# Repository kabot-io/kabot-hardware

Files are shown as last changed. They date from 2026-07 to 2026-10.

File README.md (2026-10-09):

# Kabot Hardware

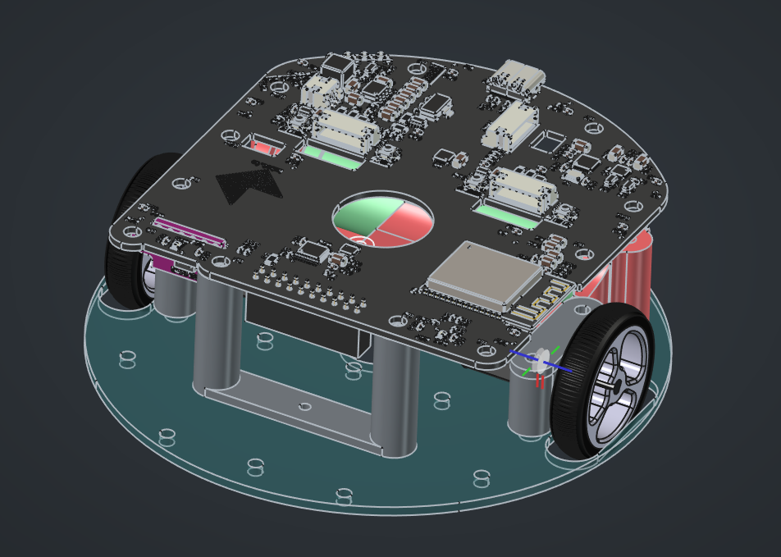
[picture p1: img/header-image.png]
Kabot robot


Kabot is an open-source, compact educational mobile robot. This repository contains its mechanical, electronic, and hardware production files.

## Project status

The hardware prototype is complete.

## FOSS toolchain

The hardware was designed entirely with free and open-source software (FOSS):

- [FreeCAD 1.1.1](https://www.freecad.org/) for the mechanical design
- [KiCad 10.0.4](https://www.kicad.org/) for the electronic design

Using these versions is recommended for the best compatibility with the source files.

## BOM

The mechanical parts are designed using [FreeCAD](https://www.freecad.org/) and 3D printed with some little exceptions, which were not viable to print due to the low cost of China-sourced parts, that is (amount for 10 robots):

- [Wheels](https://www.aliexpress.com/item/1005006221405033.html) - 20pcs
- [Torx self-tapping screws](https://www.aliexpress.com/item/1005011545930370.html) - 100pcs
- [N20 Gearmotors with 7CPR encoders](https://www.aliexpress.com/item/1005007102441781.html) - 20pcs
- [ToF distance sensor](https://www.aliexpress.com/item/1005008119148487.html) - 10pcs
- [Motor to PCB cables](https://www.aliexpress.com/item/1005007277030322.html) - 20pcs

## Electronics

The electronics has been designed using [KiCad](https://www.kicad.org/) and consist of few distinct sections (however, on a single PCB).

### Processing section  
Based on the [ESP32-S3-N16R8 MCU on Wroom-1 module](https://documentation.espressif.com/esp32-s3-wroom-1_wroom-1u_datasheet_en.pdf), which is responsible for communication with the PC, fetching data from the sensors, and executing control messages - driving the motors.

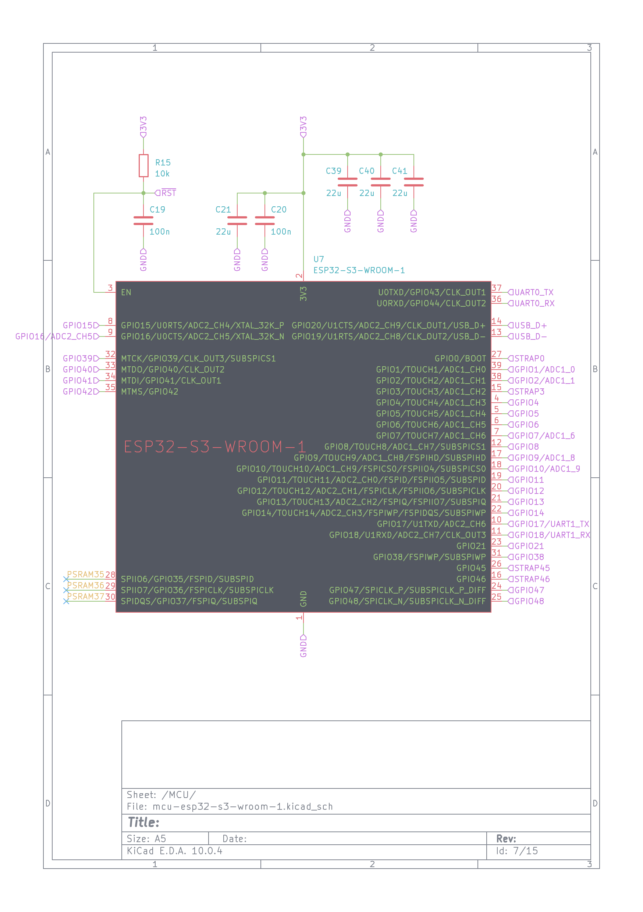
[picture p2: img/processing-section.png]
Processing section schematic


This MCU has a [built-in USB JTAG](https://docs.espressif.com/projects/esp-idf/en/stable/esp32s3/api-guides/jtag-debugging/index.html) interface, which allows for flashing and debugging the robot firmware without the need of *any* external tools, besides USB-C cable. 

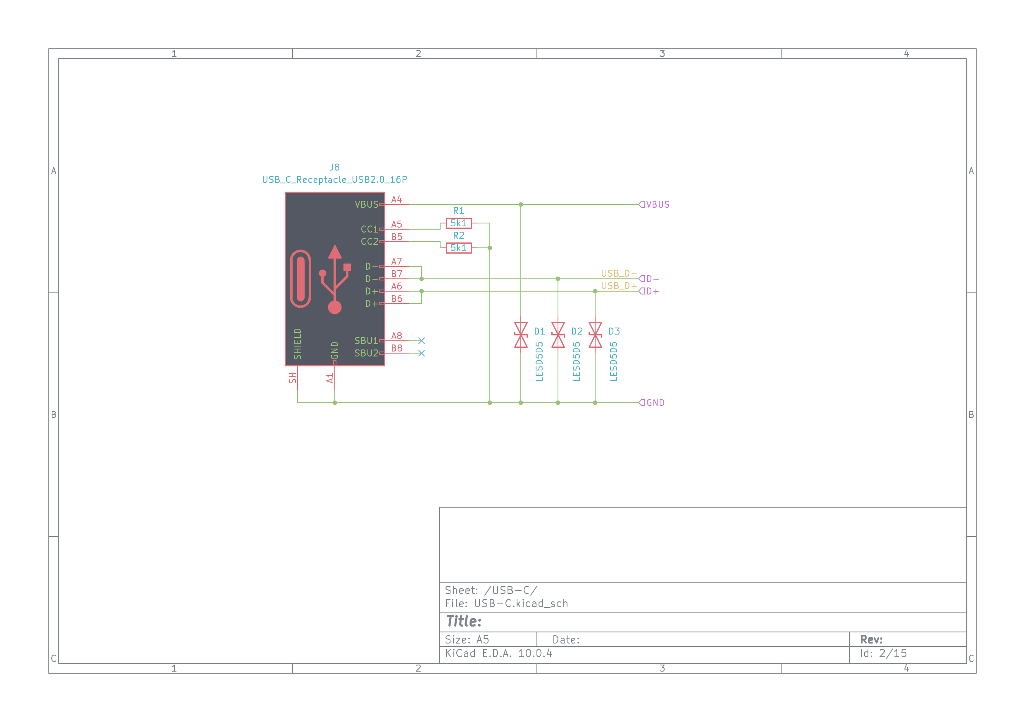
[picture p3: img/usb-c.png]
USB-C schematic


There is also onboard USB HUB ([CH334F](https://cdn-learn.adafruit.com/assets/assets/000/131/435/original/CH334DS1.PDF?1721660148)) and USB-to-serial adapter ([CH343P](https://cdn-learn.adafruit.com/assets/assets/000/134/549/original/CH343DS1.PDF?1737477957)), which allows for connecting to the robot over the raw UART interface, which exposes [first-stage bootloader](https://docs.espressif.com/projects/esp-idf/en/stable/esp32s3/api-guides/bootloader.html) logs, and a connector which allows for splitting the USB-C lanes, and injecting offboard processing units, such as embedded Linux board (instead of the beefy PC, to make the robot self-contained if needed) 

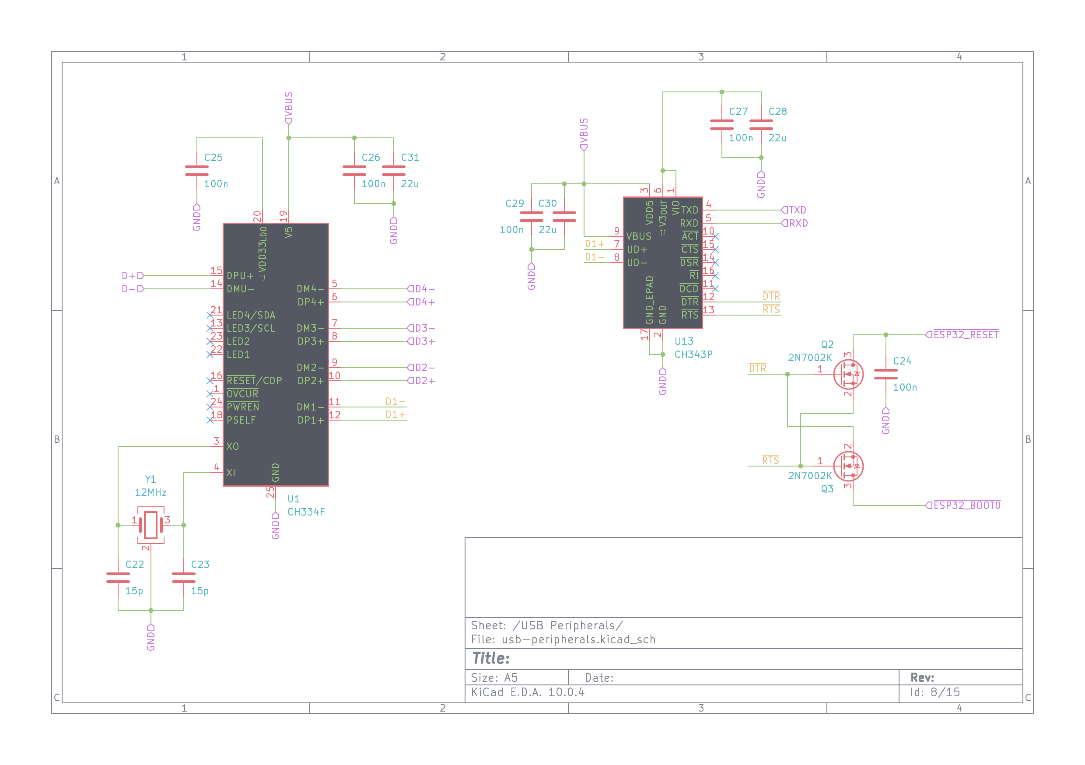
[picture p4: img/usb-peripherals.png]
USB peripherals schematic


### Power section  
The USB-C connector that is used to program the robot, is also used to charge the robot built-in battery, which is a single Lithium-Ion 18650 sized cell. The same chip is also responsible for stepping the battery voltage up to 5V, which is then fed to the motor drivers to have somehat stable motor power supply, and stabilized to 3.3V for the MCU. The chip is the thing used in powerbanks - [INJOINIC IP5306](https://www.lcsc.com/datasheet/C181692.pdf).

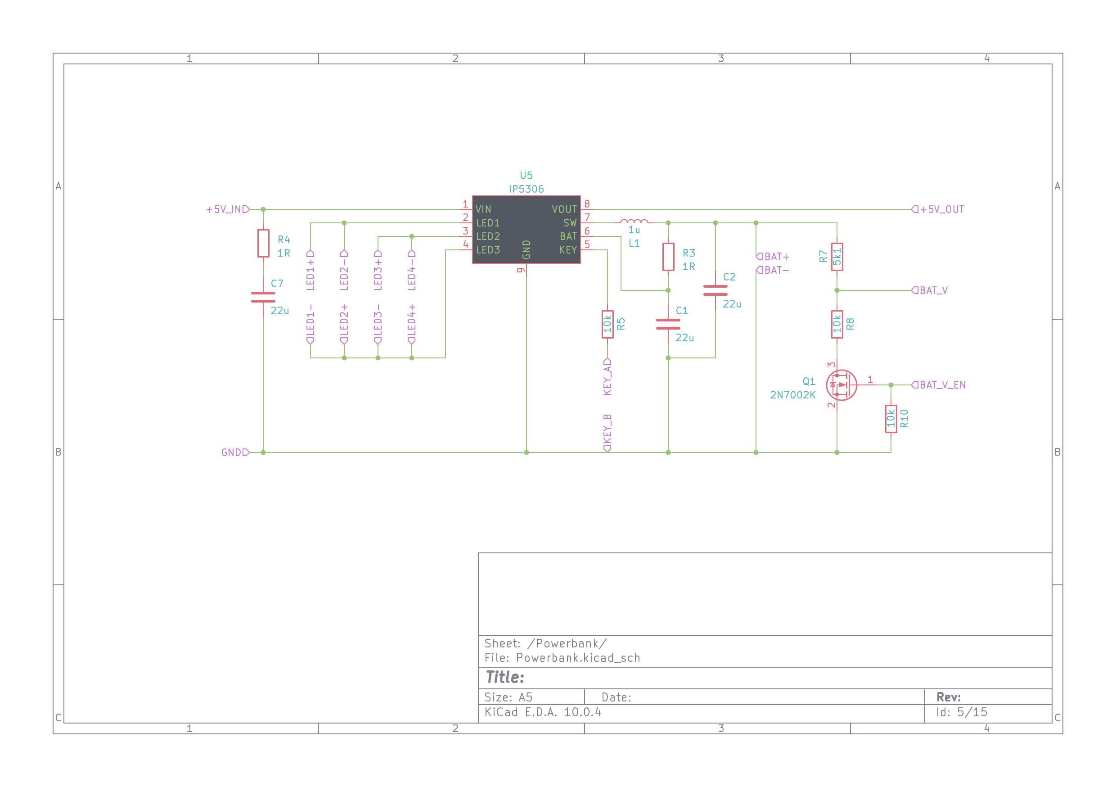
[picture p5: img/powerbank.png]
Powerbank schematic


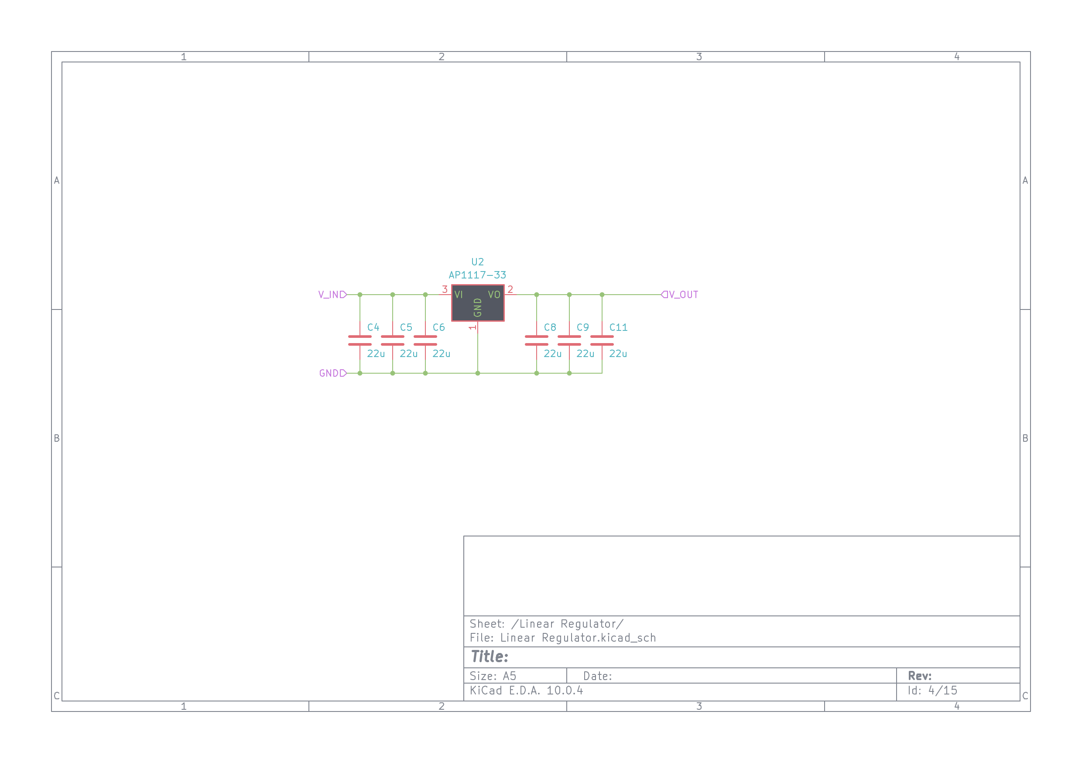
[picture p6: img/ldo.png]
LDO schematic


Motors are driven by two [DRV8837](https://www.ti.com/lit/ds/symlink/drv8838.pdf) motor drivers (up to 1.8A per motor). Each motor driver is supplied via [INA219](https://www.ti.com/lit/ds/symlink/ina219.pdf) I2C Current/Power monitor. The motors are chinese [N20 sized 298:1 micro gearmotors, equipped with magnetic incremental encoders](https://pl.aliexpress.com/item/1005007102441781.html). The power supply branch for the rest of the system also has it's own IN219 sensor. There is also voltage divider connected directly do the battery terminals (or rather semi-directly - via a switch that gets opened when the robot is not powered up, to avoid entirely draining the battery). 

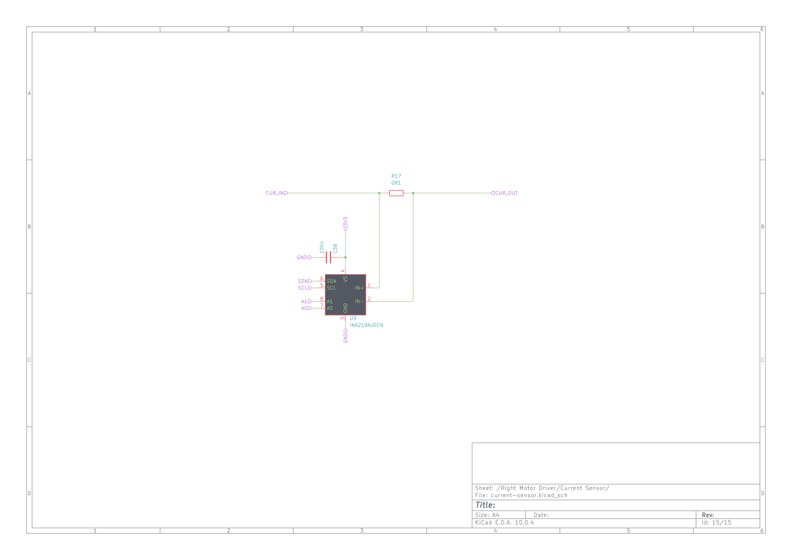
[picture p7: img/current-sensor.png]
Current sensor schematic


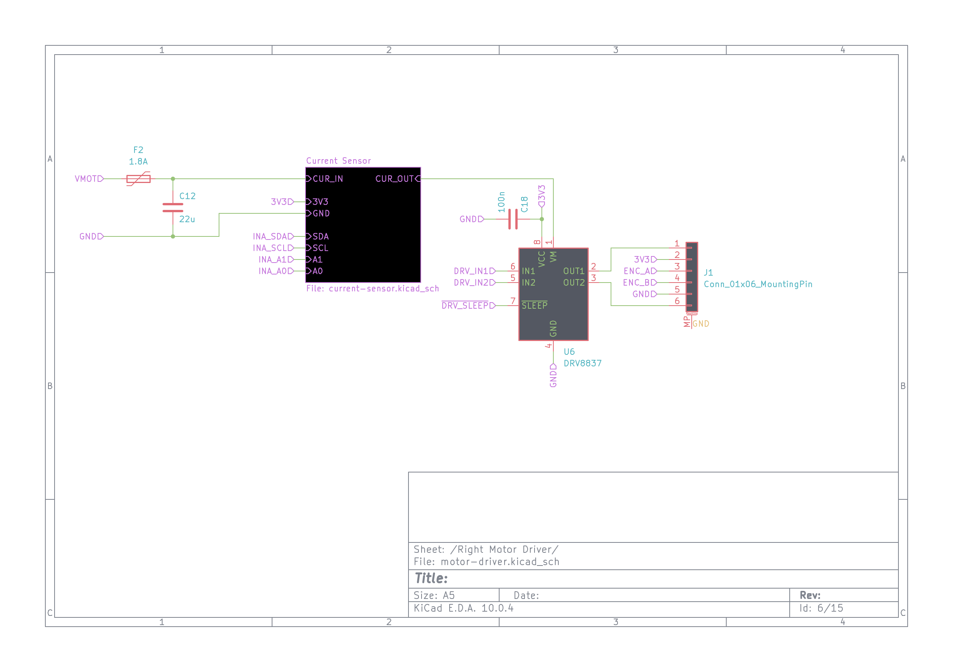
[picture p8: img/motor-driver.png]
Motor driver schematic

### Sensors section  

Besides the current sensors and encoders, robot has a bunch of on-board sensors:
- 6 Degrees of Freedon Inertial Measurement Unit: [TDK ICM-42670-L](https://datasheet.lcsc.com/datasheet/pdf/874d19cb3cf7cf4a72e58391bfc479df.pdf)
- 3 Degrees of Freedom Magnetometer: [MEMSIC MMC5603NJ](https://www.lcsc.com/datasheet/C404328.pdf)
- dual visible light sensors (left and right): [LITEON LTR-303-ALS](https://www.lcsc.com/datasheet/C364577.pdf)
- distance sensor - [ST VL53L0X](https://www.st.com/resource/en/datasheet/vl53l0x.pdf) on the GY-530 footprint module - this allows for supplying different distance sensors, sucha as 8x8 grid [ST VL53L5X](https://www.st.com/resource/en/datasheet/vl53l5cx.pdf) ToF sensor

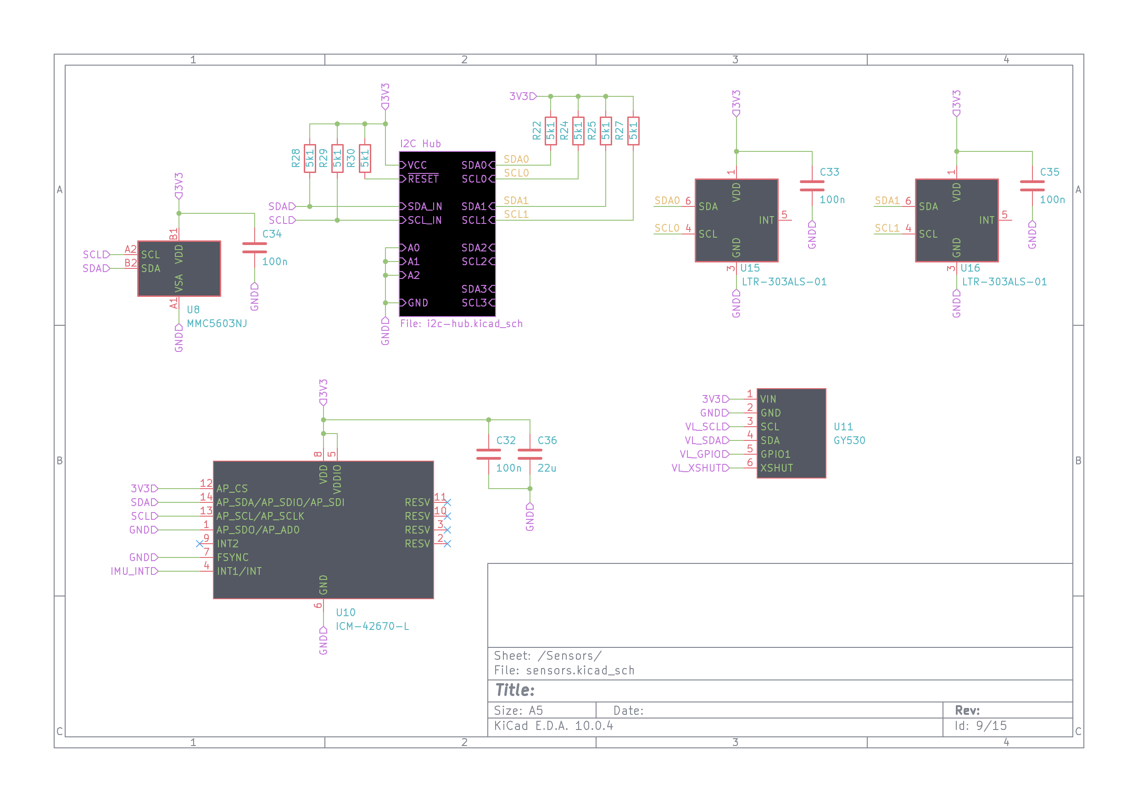
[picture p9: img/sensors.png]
Sensors schematic

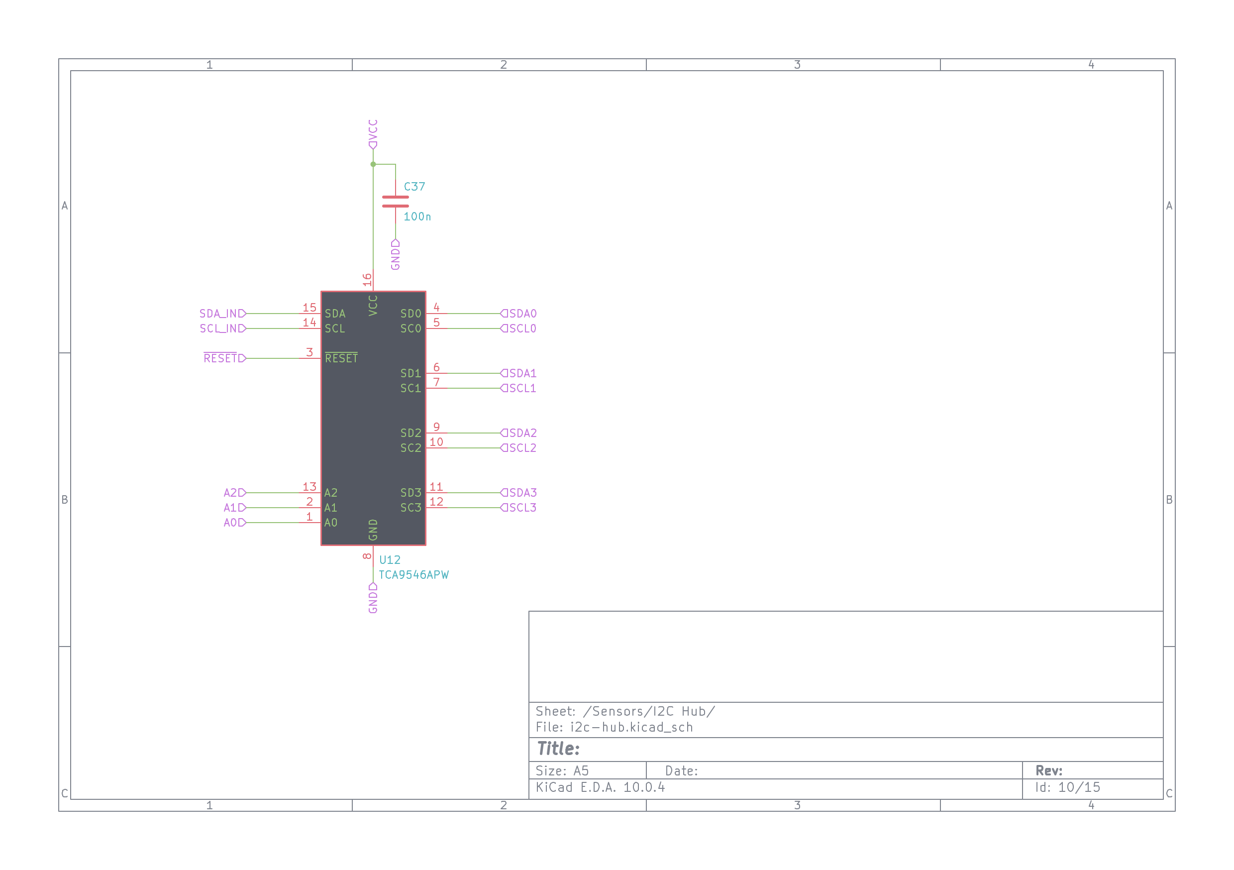
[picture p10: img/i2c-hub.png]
I2C hub schematic


These allow for implementing a wide variety of algorithms - from simple [BEAM](https://en.wikipedia.org/wiki/BEAM_robotics)-like photovores, trough IMU sensor fusion up to localization and mapping.

The board also supplies a bunch of addresable RGB LEDs.

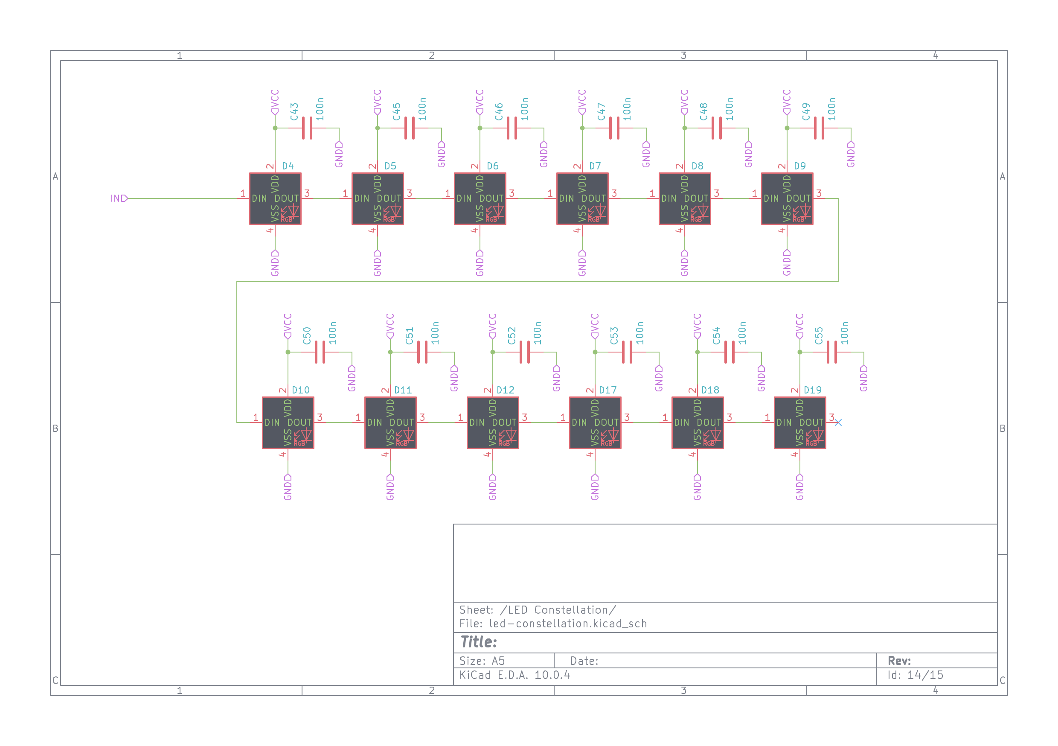
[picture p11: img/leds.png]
LEDs schematic


## Repository structure

| Directory | Contents |
| --- | --- |
| [`freecad/`](freecad/) | FreeCAD mechanical source files for the chassis, battery holder, motor mounts, wheels, and related parts. |
| [`kicad/`](kicad/) | KiCad schematics, PCB layout, symbols, footprints, and supporting EDA files. |
| [`production/`](production/) | Files used to manufacture the PCB and print the chassis, including Gerber and drill files, a bill of materials (BOM), and pick-and-place data. |

## License

Copyright 2026 Krzysztof Pochwała.

The hardware design files are available under the [Creative Commons Attribution-NonCommercial-ShareAlike 4.0 International license](LICENSE.md) (CC BY-NC-SA 4.0). You may share and adapt the files with attribution, for non-commercial purposes, provided adaptations are distributed under the same license.

## More information

Visit [kabot.io](https://kabot.io/).

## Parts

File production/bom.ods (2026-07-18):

 | version | qty | link | Price @ lot | Price @ 1 | need | price sum
Motor + encoder | 50RPM | 1 | https://pl.aliexpress.com/item/1005007571722097.html | 6,53 | 6,53 | 2 | 13,06
battery | 10pcs | 10 | https://pl.aliexpress.com/item/1005008078553867.html | 24,91 | 2,491 | 1 | 2,491
wheels | white | 10 | https://pl.aliexpress.com/item/1005006221405033.html | 4 | 0,4 | 2 | 0,8
acc+gyro | ICM-42670-L | 1 | https://www.lcsc.com/product-detail/C49073546.html | 1,86 | 1,86 | 1 | 1,86
magnetometer | MMC5603NJ | 5 | https://www.lcsc.com/product-detail/C404328.html | 1,44 | 0,288 | 1 | 0,288
current sensor | INA219 | 10 | https://www.lcsc.com/product-detail/C87469.html | 6,3 | 0,63 | 2 | 1,26
motor driver | DRV8837 | 5 | https://www.lcsc.com/product-detail/C191000.html | 0,57 | 0,114 | 2 | 0,228
shock absorber | M3 White 50pcs | 50 | https://pl.aliexpress.com/item/1005003323071003.html | 2,08 | 0,0416 | 4 | 0,1664
filament | PETG-BK-3KG | 3000 | https://pl.aliexpress.com/item/1005007633497332.html | 36,86 | 0,0122866666666667 | 200 | 2,45733333333333
8x8 tof VL53L5X |  | 1 | https://pl.aliexpress.com/item/1005009716186025.html | 9,79 | 9,79 | 1 | 9,79
ESP32 | ESP32-S3-WROOM-N16R8 | 1 | https://www.lcsc.com/product-detail/C2913202.html | 5,21 | 5,21 | 0 | 0
Camera | OV3660 | 1 | https://pl.aliexpress.com/item/1005008605438383.html | 3,39 | 3,39 | 1 | 3,39
Motor Connector | ZX-ZH1.5-6PWT | 5 | https://www.lcsc.com/product-detail/C19272409.html | 0,33 | 0,066 | 2 | 0,132
Battery Connector | ZX-ZH1.5-2PWT | 10 | https://www.lcsc.com/product-detail/C19272405.html | 0,44 | 0,044 | 1 | 0,044
Motor Cable | 10CM 10PCS Double head 6p | 10 | https://pl.aliexpress.com/item/1005007277030322.html | 4,37 | 0,437 | 2 | 0,874
Battery Cable | 10CM 10PCS Single head 2p | 10 | https://pl.aliexpress.com/item/1005007277030322.html | 1,66 | 0,166 | 1 | 0,166
Sensor Connector | MF254VS-12-20-0743 | 1 | https://www.lcsc.com/product-detail/C911394.html | 0,53 | 0,53 | 1 | 0,53
RGB LED | WS2812 | 5 | zwrócić uwagę na zasilanie 3.3V | 0,5 | 0,1 | 7 | 0,7
Powerbank | IP5306 | 5 | https://www.lcsc.com/product-detail/C181692.html | 1,41 | 0,282 | 1 | 0,282
light sensor |  |  | TEMT6000, ale drogi |  |  | 2 | 0
 |  |  |  |  |  |  | 0
17,2033333333333 |  |  |  |  |  |  | 0
 |  |  |  |  |  |  | 0
 |  |  |  |  |  |  | 0
 |  |  |  |  |  |  | 0
 |  |  |  |  |  |  | 0
 |  |  |  |  |  |  | 0
 |  |  |  |  |  |  | 0
 |  |  |  |  |  |  | 0
 |  |  |  |  |  |  | 0
 |  |  |  |  |  |  | 0
 |  |  |  |  |  |  | 38,5187333333333

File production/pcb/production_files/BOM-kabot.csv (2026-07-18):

Comment | Designator | Footprint | LCSC | Quantity
0R1 | R17,R23,R26 | R_1206_3216Metric | C25334 | 3
1.8A | F1,F2,F3,F4 | Fuse_1206_3216Metric | C5375706 | 4
100n | C13,C18,C19,C20,C24,C25,C26,C27,C29,C32,C33,C34,C35,C37,C38,C42,C43,C44,C45,C46,C47,C48,C49,C50,C51,C52,C53,C54,C55 | C_0603_1608Metric | C14663 | 29
10k | R10,R15,R5,R8 | R_0603_1608Metric | C25804 | 4
12MHz | Y1 | Crystal_SMD_3225-4Pin_3.2x2.5mm | C9002 | 1
15p | C22,C23 | C_0603_1608Metric | C1644 | 2
1R | R3,R4 | R_0603_1608Metric | C22936 | 2
1u | L1 | L_Changjiang_FNR5045S | C436396 | 1
22u | C1,C10,C11,C12,C14,C2,C21,C28,C30,C31,C36,C39,C4,C40,C41,C5,C6,C7,C8,C9 | C_1206_3216Metric | C12891 | 20
2N7002K | Q1,Q2,Q3 | SOT-23 | C8545 | 3
5k1 | R1,R11,R12,R13,R14,R16,R18,R19,R2,R20,R21,R22,R24,R25,R27,R28,R29,R30,R7,R9 | R_0603_1608Metric | C23186 | 20
AP1117-33 | U2 | SOT-223-3_TabPin2 | C6186 | 1
BAT | J5 | JST_ZH_S2B-ZR-SM4A-TF_1x02-1MP_P1.50mm_Horizontal | C19272405 | 1
CH334F | U1 | QFN-24-1EP_4x4mm_P0.5mm_EP2.7x2.7mm | C5187527 | 1
CH343P | U13 | WCH_QFN-16-1EP_3x3mm_P0.5mm_EP1.8x1.8mm | C2846043 | 1
Conn_01x06_MountingPin | J1,J101,J102 | JST_ZH_S6B-ZR-SM4A-TF_1x06-1MP_P1.50mm_Horizontal | C19272409 | 3
DRV8837 | U14,U6 | WSON-8-1EP_2x2mm_P0.5mm_EP0.9x1.6mm | C39159 | 2
ESP32-S3-WROOM-1 | U7 | ESP32-S3-WROOM-1 | C2913202 | 1
ICM-42670-L | U10 | LGA-14_3x2.5mm_P0.5mm_LayoutBorder3x4y | C49073546 | 1
INA219AxDCN | U17,U18,U9 | SOT-23-8 | C87469 | 3
IP5306 | U5 | Diodes_SO-8EP | C181692 | 1
LED | D13,D14,D15,D16 | LED_0603_1608Metric | C2290 | 4
LESD5D5 | D1,D2,D3 | D_SOD-523 | C383211 | 3
LP5012 | U4 | WQFN-20-1EP_3x3mm_P0.4mm_EP1.7x1.7mm | C1849481 | 1
LTR-303ALS-01 | U15,U16 | Lite-On_LTR-303ALS-01 | C364577 | 2
MMC5603NJ | U8 | WLP-4_0.86x0.86mm_P0.4mm | C404328 | 1
SW_Push | SW1,SW2,SW3,SW4 | SW_Push_SPST_NO_Alps_SKRK | C720477 | 4
TCA9546APW | U12 | TSSOP-16_4.4x5mm_P0.65mm | C42420613 | 1
USB_C_Receptacle_USB2.0_16P | J8 | USB_C_Receptacle_GCT_USB4105-xx-A_16P_TopMnt_Horizontal | C668624 | 1
XL2121RGBC-WS2812B | D10,D11,D12,D17,D18,D19,D4,D5,D6,D7,D8,D9 | LED_ASMB-KTF0-0A306 | C5349957 | 12
GY530 | U11 | GY530 |  | 1

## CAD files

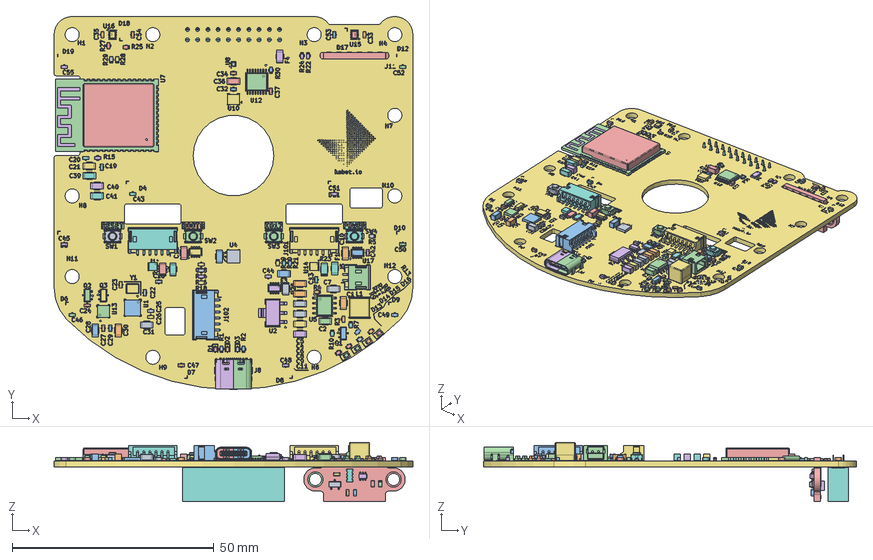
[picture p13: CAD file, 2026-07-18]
freecad/MainBoard2.FCStd
89.0 x 92.5 x 14.7 mm
D_SOD_523
C_1206_3216Metric
C_1206_3216Metric002
C_0603_1608Metric
C_1206_3216Metric004
C_0603_1608Metric002
C_0603_1608Metric004
C_0603_1608Metric006
C_1206_3216Metric006
C_0603_1608Metric008
ZH_Connector_SMT_Side
TSSOP-16_4.4x5mm_P0.65mm
R_0603_1608Metric
C_0603_1608Metric010
LGA_14_3x25mm_P05mm_LayoutBorder3x4y
R_0603_1608Metric002
R_0603_1608Metric004
C_0603_1608Metric012
USB_C_Receptacle_16P_TopMnt_Horizontal_GCT_USB4105-xx-A
USB_C_Receptacle_16P_TopMnt_Horizontal_GCT_USB4105-xx-A001
USB_C_Receptacle_16P_TopMnt_Horizontal_GCT_USB4105-xx-A002
USB_C_Receptacle_16P_TopMnt_Horizontal_GCT_USB4105-xx-A003
USB_C_Receptacle_16P_TopMnt_Horizontal_GCT_USB4105-xx-A004
USB_C_Receptacle_16P_TopMnt_Horizontal_GCT_USB4105-xx-A005
USB_C_Receptacle_16P_TopMnt_Horizontal_GCT_USB4105-xx-A006
USB_C_Receptacle_16P_TopMnt_Horizontal_GCT_USB4105-xx-A007
USB_C_Receptacle_16P_TopMnt_Horizontal_GCT_USB4105-xx-A008
USB_C_Receptacle_16P_TopMnt_Horizontal_GCT_USB4105-xx-A009
USB_C_Receptacle_16P_TopMnt_Horizontal_GCT_USB4105-xx-A010
USB_C_Receptacle_16P_TopMnt_Horizontal_GCT_USB4105-xx-A011
USB_C_Receptacle_16P_TopMnt_Horizontal_GCT_USB4105-xx-A012
USB_C_Receptacle_16P_TopMnt_Horizontal_GCT_USB4105-xx-A013
USB_C_Receptacle_16P_TopMnt_Horizontal_GCT_USB4105-xx-A014
USB_C_Receptacle_16P_TopMnt_Horizontal_GCT_USB4105-xx-A015
USB_C_Receptacle_16P_TopMnt_Horizontal_GCT_USB4105-xx-A016
USB_C_Receptacle_16P_TopMnt_Horizontal_GCT_USB4105-xx-A017
USB_C_Receptacle_16P_TopMnt_Horizontal_GCT_USB4105-xx-A018
USB_C_Receptacle_16P_TopMnt_Horizontal_GCT_USB4105-xx-A019
USB_C_Receptacle_16P_TopMnt_Horizontal_GCT_USB4105-xx-A020
USB_C_Receptacle_16P_TopMnt_Horizontal_GCT_USB4105-xx-A021
USB_C_Receptacle_16P_TopMnt_Horizontal_GCT_USB4105-xx-A022
USB_C_Receptacle_16P_TopMnt_Horizontal_GCT_USB4105-xx-A023
USB_C_Receptacle_16P_TopMnt_Horizontal_GCT_USB4105-xx-A024
USB_C_Receptacle_16P_TopMnt_Horizontal_GCT_USB4105-xx-A025
USB_C_Receptacle_16P_TopMnt_Horizontal_GCT_USB4105-xx-A026
USB_C_Receptacle_16P_TopMnt_Horizontal_GCT_USB4105-xx-A027
USB_C_Receptacle_16P_TopMnt_Horizontal_GCT_USB4105-xx-A028
USB_C_Receptacle_16P_TopMnt_Horizontal_GCT_USB4105-xx-A029
USB_C_Receptacle_16P_TopMnt_Horizontal_GCT_USB4105-xx-A030
USB_C_Receptacle_16P_TopMnt_Horizontal_GCT_USB4105-xx-A031
USB_C_Receptacle_16P_TopMnt_Horizontal_GCT_USB4105-xx-A032
USB_C_Receptacle_16P_TopMnt_Horizontal_GCT_USB4105-xx-A033
USB_C_Receptacle_16P_TopMnt_Horizontal_GCT_USB4105-xx-A034
USB_C_Receptacle_16P_TopMnt_Horizontal_GCT_USB4105-xx-A035
L_Changjiang_FNR5045S
SW_Push_SPST_NO_Alps_SKRK
C_0603_1608Metric014
C_0603_1608Metric016
SOT-23
LED_0603_1608Metric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

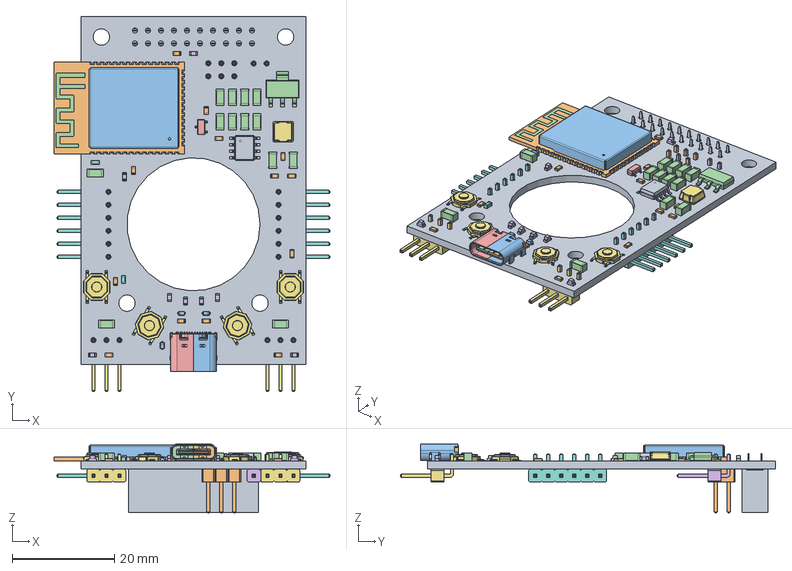
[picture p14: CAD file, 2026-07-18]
freecad/MainBoard.FCStd
53.9 x 73.3 x 13.4 mm
Pcb_f0d5
R3_R_0603_1608Metric_ec17440d7075 x 13
D2_D_SOD_523_221bc2778bf3 x 3
C1_C_1206_3216Metric_7c554c30f47e x 13
Q1_SOT-23_b5c16fc596b7
D7_LED_0603_1608Metric_c0ab641bd838 x 8
SW4_SW_SPST_TL3342_1d188f60b101 x 4
C12_C_0603_1608Metric_c1b05ed436e2 x 2
U5_PowerIntegrations_SO-8_8ec1130fc03a
C0201_20210301.STEP^C0201_20210301.STEP_Submodel-C0201_part_DesignRootModel_PCB_ESP32-S3-WROOM-1_V1(2)_PCB_ESP32-S3-WROOM-1_V1
L0201_20210301.STEP^L0201_20210301.STEP_Submodel-L0201_part_DesignRootModel_PCB_ESP32-S3-WROOM-1_V1(2)_PCB_ESP32-S3-WROOM-1_V1
C0402_20210301.STEP^C0402_20210301.STEP_Submodel-C0402_part_DesignRootModel_PCB_ESP32-S3-WROOM-1_V1(2)_PCB_ESP32-S3-WROOM-1_V1
R0201_20210301.STEP^R0201_20210301.STEP_Submodel-R0201_part_DesignRootModel_PCB_ESP32-S3-WROOM-1_V1(2)_PCB_ESP32-S3-WROOM-1_V1
R0201_20210301.STEP^R0201_20210301.STEP_Submodel-R0201_part_DesignRootModel_PCB_ESP32-S3-WROOM-1_V1(2)_PCB_ESP32-S3-WROOM-1_V001
R0201_20210301.STEP^R0201_20210301.STEP_Submodel-R0201_part_DesignRootModel_PCB_ESP32-S3-WROOM-1_V1(2)_PCB_ESP32-S3-WROOM-1_V002
R0201_20210301.STEP^R0201_20210301.STEP_Submodel-R0201_part_DesignRootModel_PCB_ESP32-S3-WROOM-1_V1(2)_PCB_ESP32-S3-WROOM-1_V004
R0201_20210301.STEP^R0201_20210301.STEP_Submodel-R0201_part_DesignRootModel_PCB_ESP32-S3-WROOM-1_V1(2)_PCB_ESP32-S3-WROOM-1_V005
R0201_20210301.STEP^R0201_20210301.STEP_Submodel-R0201_part_DesignRootModel_PCB_ESP32-S3-WROOM-1_V1(2)_PCB_ESP32-S3-WROOM-1_V006
R0201_20210301.STEP^R0201_20210301.STEP_Submodel-R0201_part_DesignRootModel_PCB_ESP32-S3-WROOM-1_V1(2)_PCB_ESP32-S3-WROOM-1_V008
R0201_20210301.STEP^R0201_20210301.STEP_Submodel-R0201_part_DesignRootModel_PCB_ESP32-S3-WROOM-1_V1(2)_PCB_ESP32-S3-WROOM-1_V009
R0201_20210301.STEP^R0201_20210301.STEP_Submodel-R0201_part_DesignRootModel_PCB_ESP32-S3-WROOM-1_V1(2)_PCB_ESP32-S3-WROOM-1_V010
R0201_20210301.STEP^R0201_20210301.STEP_Submodel-R0201_part_DesignRootModel_PCB_ESP32-S3-WROOM-1_V1(2)_PCB_ESP32-S3-WROOM-1_V012
R0201_20210301.STEP^R0201_20210301.STEP_Submodel-R0201_part_DesignRootModel_PCB_ESP32-S3-WROOM-1_V1(2)_PCB_ESP32-S3-WROOM-1_V013
R0201_20210301.STEP^R0201_20210301.STEP_Submodel-R0201_part_DesignRootModel_PCB_ESP32-S3-WROOM-1_V1(2)_PCB_ESP32-S3-WROOM-1_V014
R0201_20210301.STEP^R0201_20210301.STEP_Submodel-R0201_part_DesignRootModel_PCB_ESP32-S3-WROOM-1_V1(2)_PCB_ESP32-S3-WROOM-1_V016
R0201_20210301.STEP^R0201_20210301.STEP_Submodel-R0201_part_DesignRootModel_PCB_ESP32-S3-WROOM-1_V1(2)_PCB_ESP32-S3-WROOM-1_V017
R0201_20210301.STEP^R0201_20210301.STEP_Submodel-R0201_part_DesignRootModel_PCB_ESP32-S3-WROOM-1_V1(2)_PCB_ESP32-S3-WROOM-1_V018
R0201_20210301.STEP^R0201_20210301.STEP_Submodel-R0201_part_DesignRootModel_PCB_ESP32-S3-WROOM-1_V1(2)_PCB_ESP32-S3-WROOM-1_V020
R0201_20210301.STEP^R0201_20210301.STEP_Submodel-R0201_part_DesignRootModel_PCB_ESP32-S3-WROOM-1_V1(2)_PCB_ESP32-S3-WROOM-1_V021
R0201_20210301.STEP^R0201_20210301.STEP_Submodel-R0201_part_DesignRootModel_PCB_ESP32-S3-WROOM-1_V1(2)_PCB_ESP32-S3-WROOM-1_V022
R0201_20210301.STEP^R0201_20210301.STEP_Submodel-R0201_part_DesignRootModel_PCB_ESP32-S3-WROOM-1_V1(2)_PCB_ESP32-S3-WROOM-1_V024
R0201_20210301.STEP^R0201_20210301.STEP_Submodel-R0201_part_DesignRootModel_PCB_ESP32-S3-WROOM-1_V1(2)_PCB_ESP32-S3-WROOM-1_V025
R0201_20210301.STEP^R0201_20210301.STEP_Submodel-R0201_part_DesignRootModel_PCB_ESP32-S3-WROOM-1_V1(2)_PCB_ESP32-S3-WROOM-1_V026
R0201_20210301.STEP^R0201_20210301.STEP_Submodel-R0201_part_DesignRootModel_PCB_ESP32-S3-WROOM-1_V1(2)_PCB_ESP32-S3-WROOM-1_V028
R0201_20210301.STEP^R0201_20210301.STEP_Submodel-R0201_part_DesignRootModel_PCB_ESP32-S3-WROOM-1_V1(2)_PCB_ESP32-S3-WROOM-1_V029
R0201_20210301.STEP^R0201_20210301.STEP_Submodel-R0201_part_DesignRootModel_PCB_ESP32-S3-WROOM-1_V1(2)_PCB_ESP32-S3-WROOM-1_V030
L0201_20210301.STEP^L0201_20210301.STEP_Submodel-L0201_part_DesignRootModel_PCB_ESP32-S3-WROOM-1_V1(2)_PCB_ESP32-S3-WROOM-1_V001
L0201_20210301.STEP^L0201_20210301.STEP_Submodel-L0201_part_DesignRootModel_PCB_ESP32-S3-WROOM-1_V1(2)_PCB_ESP32-S3-WROOM-1_V002
C0201_20210301.STEP^C0201_20210301.STEP_Submodel-C0201_part_DesignRootModel_PCB_ESP32-S3-WROOM-1_V1(2)_PCB_ESP32-S3-WROOM-1_V001
C0201_20210301.STEP^C0201_20210301.STEP_Submodel-C0201_part_DesignRootModel_PCB_ESP32-S3-WROOM-1_V1(2)_PCB_ESP32-S3-WROOM-1_V002
C0201_20210301.STEP^C0201_20210301.STEP_Submodel-C0201_part_DesignRootModel_PCB_ESP32-S3-WROOM-1_V1(2)_PCB_ESP32-S3-WROOM-1_V003
C0201_20210301.STEP^C0201_20210301.STEP_Submodel-C0201_part_DesignRootModel_PCB_ESP32-S3-WROOM-1_V1(2)_PCB_ESP32-S3-WROOM-1_V004
C0201_20210301.STEP^C0201_20210301.STEP_Submodel-C0201_part_DesignRootModel_PCB_ESP32-S3-WROOM-1_V1(2)_PCB_ESP32-S3-WROOM-1_V005
C0201_20210301.STEP^C0201_20210301.STEP_Submodel-C0201_part_DesignRootModel_PCB_ESP32-S3-WROOM-1_V1(2)_PCB_ESP32-S3-WROOM-1_V006
C0201_20210301.STEP^C0201_20210301.STEP_Submodel-C0201_part_DesignRootModel_PCB_ESP32-S3-WROOM-1_V1(2)_PCB_ESP32-S3-WROOM-1_V007
C0201_20210301.STEP^C0201_20210301.STEP_Submodel-C0201_part_DesignRootModel_PCB_ESP32-S3-WROOM-1_V1(2)_PCB_ESP32-S3-WROOM-1_V008
C0201_20210301.STEP^C0201_20210301.STEP_Submodel-C0201_part_DesignRootModel_PCB_ESP32-S3-WROOM-1_V1(2)_PCB_ESP32-S3-WROOM-1_V009
C0201_20210301.STEP^C0201_20210301.STEP_Submodel-C0201_part_DesignRootModel_PCB_ESP32-S3-WROOM-1_V1(2)_PCB_ESP32-S3-WROOM-1_V010
C0201_20210301.STEP^C0201_20210301.STEP_Submodel-C0201_part_DesignRootModel_PCB_ESP32-S3-WROOM-1_V1(2)_PCB_ESP32-S3-WROOM-1_V011
C0201_20210301.STEP^C0201_20210301.STEP_Submodel-C0201_part_DesignRootModel_PCB_ESP32-S3-WROOM-1_V1(2)_PCB_ESP32-S3-WROOM-1_V012
C0201_20210301.STEP^C0201_20210301.STEP_Submodel-C0201_part_DesignRootModel_PCB_ESP32-S3-WROOM-1_V1(2)_PCB_ESP32-S3-WROOM-1_V013
trace_1^Submodel-MINI-ANT-TYPEB_668419613_part_DesignRootModel_PCB_ESP32-S3-WROOM-1_V1(2)_PCB_ESP32-S3-WROOM-1_V1
DFN1006.STEP^DFN1006.STEP_Submodel-SOD882_part_DesignRootModel_PCB_ESP32-S3-WROOM-1_V1(2)_PCB_ESP32-S3-WROOM-1_V1
SOP8_rev1_20210308.STEP^SOP8_rev1_20210308.STEP_Submodel-SOP8_1P27_6P6_part_DesignRootModel_PCB_ESP32-S3-WROOM-1_V1(2)_PCB_ESP32-S3-WROOM-1_V1
XTAL3225_20210301.STEP^XTAL3225_20210301.STEP_Submodel-XTAL3225_part_DesignRootModel_PCB_ESP32-S3-WROOM-1_V1(2)_PCB_ESP32-S3-WROOM-1_V1
XTAL3225_20210301.STEP^XTAL3225_20210301.STEP_Submodel-XTAL3225_part_DesignRootModel_PCB_ESP32-S3-WROOM-1_V1(2)_PCB_ESP32-S3-WROOM-1_V001
XTAL3225_20210301.STEP^XTAL3225_20210301.STEP_Submodel-XTAL3225_part_DesignRootModel_PCB_ESP32-S3-WROOM-1_V1(2)_PCB_ESP32-S3-WROOM-1_V002
XTAL3225_20210301.STEP^XTAL3225_20210301.STEP_Submodel-XTAL3225_part_DesignRootModel_PCB_ESP32-S3-WROOM-1_V1(2)_PCB_ESP32-S3-WROOM-1_V003
XTAL3225_20210301.STEP^XTAL3225_20210301.STEP_Submodel-XTAL3225_part_DesignRootModel_PCB_ESP32-S3-WROOM-1_V1(2)_PCB_ESP32-S3-WROOM-1_V004
ESP32-S3_20210301.STEP^ESP32-S3_20210301.STEP_Submodel-QFN56_0P4_7_part_DesignRootModel_PCB_ESP32-S3-WROOM-1_V1(2)_PCB_ESP32-S3-WROOM-1_V1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

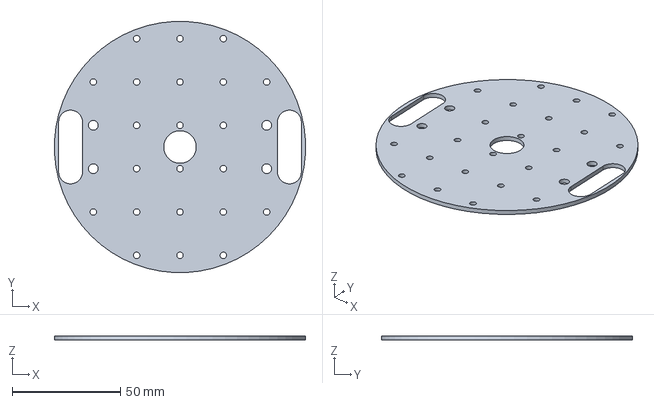
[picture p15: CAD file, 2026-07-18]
freecad/Base.FCStd
115.8 x 115.8 x 2.00 mm

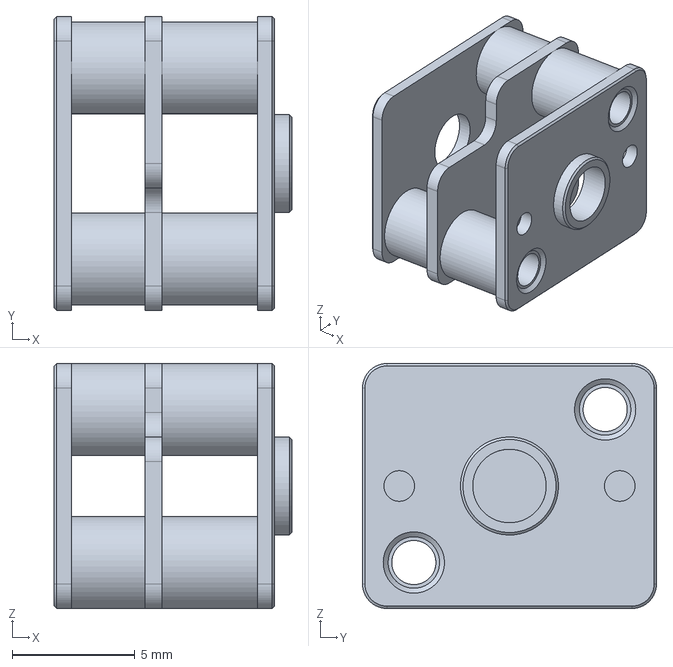
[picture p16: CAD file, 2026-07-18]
freecad/N20/Gearbox.FCStd
9.70 x 12.0 x 10.0 mm

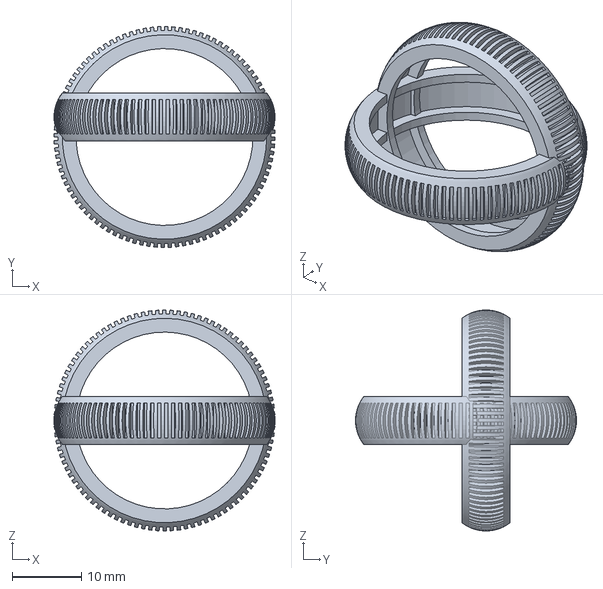
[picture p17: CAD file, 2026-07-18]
freecad/Wheel/Tire.FCStd
32.0 x 32.0 x 32.0 mm
Tire x 2

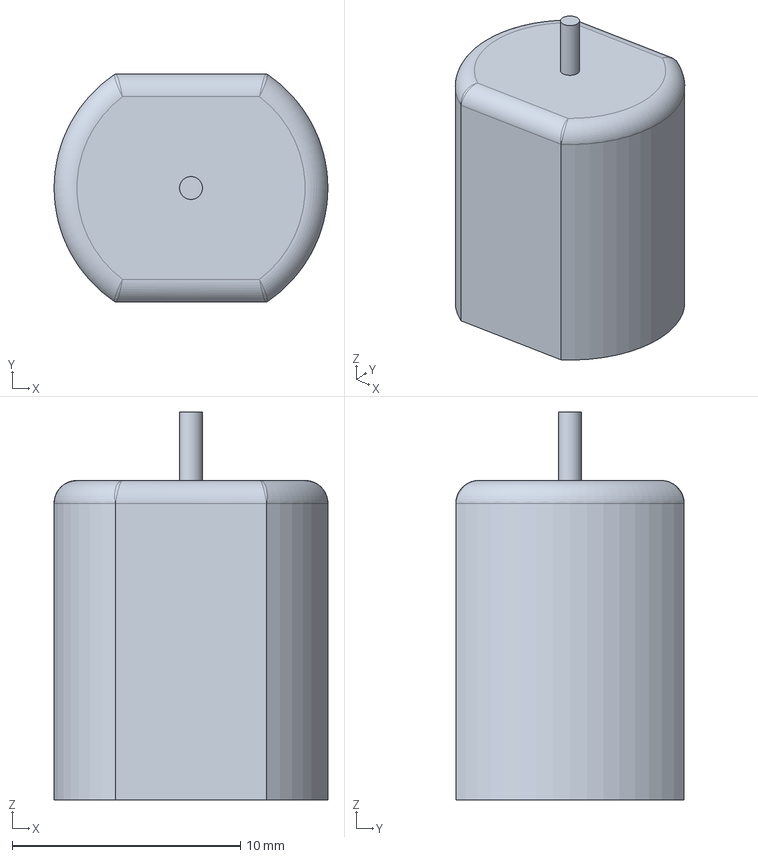
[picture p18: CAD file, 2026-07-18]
freecad/N20/Motor.FCStd
12.0 x 10.0 x 17.0 mm

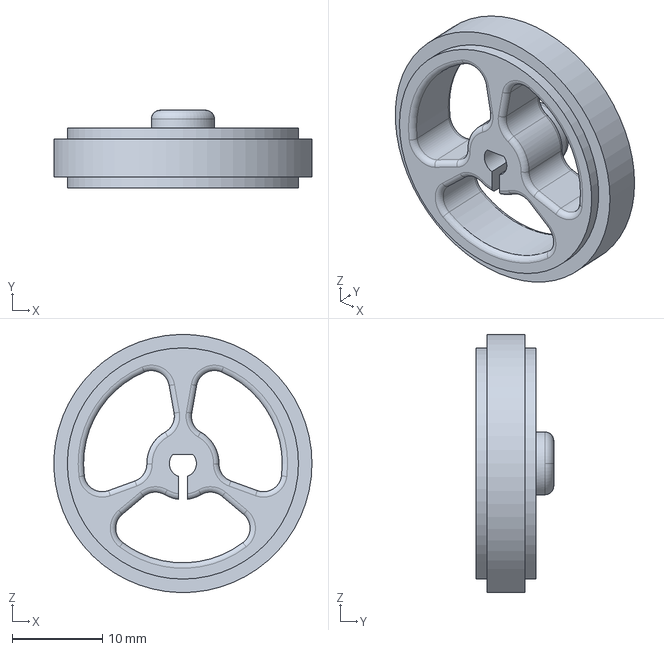
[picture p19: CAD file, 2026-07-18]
freecad/Wheel/Rim.FCStd
28.6 x 8.60 x 28.6 mm

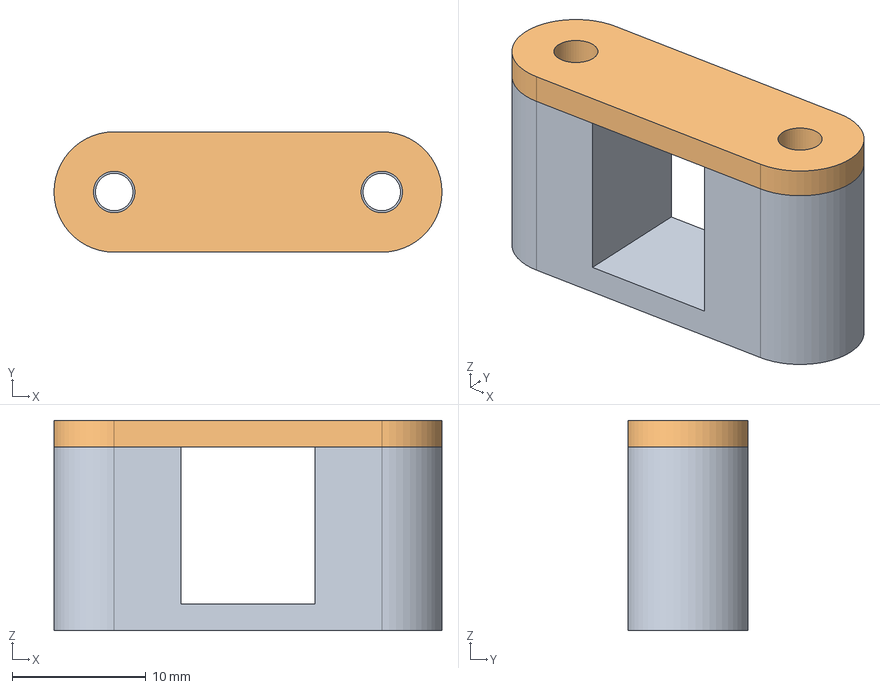
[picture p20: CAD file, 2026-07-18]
freecad/MinimalMotorHolder.FCStd
29.0 x 9.00 x 15.7 mm
Base
Top

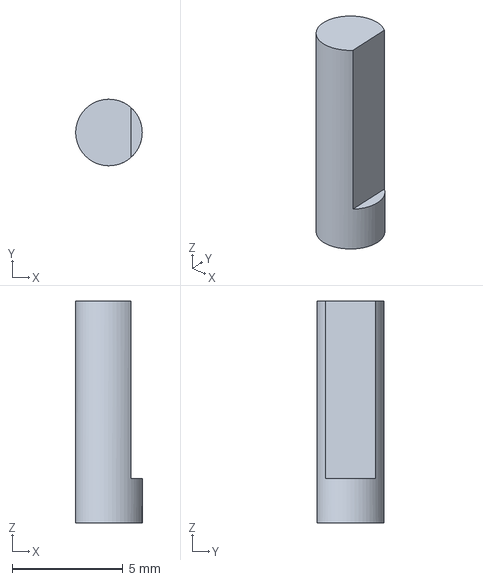
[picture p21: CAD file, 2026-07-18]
freecad/N20/Shaft.FCStd
3.00 x 3.00 x 10.0 mm

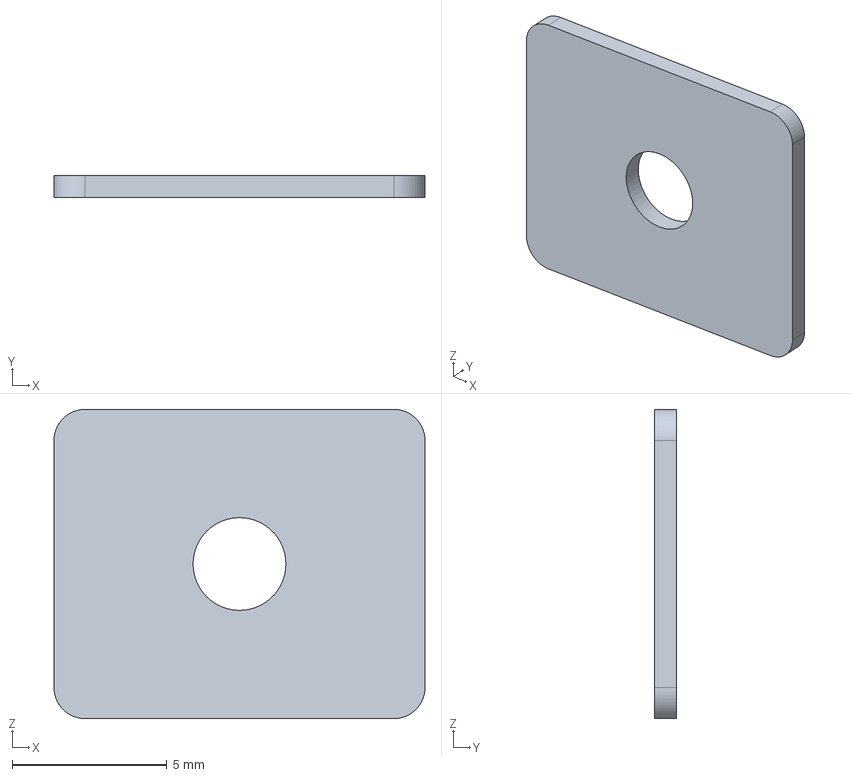
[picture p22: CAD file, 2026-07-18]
freecad/N20/plate.FCStd
12.0 x 0.7 x 10.0 mm

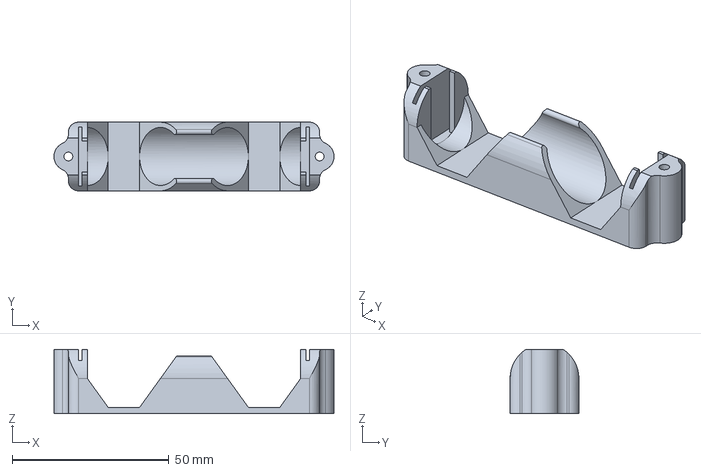
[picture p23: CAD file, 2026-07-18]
freecad/BatteryHolder.FCStd
89.2 x 21.9 x 20.5 mm

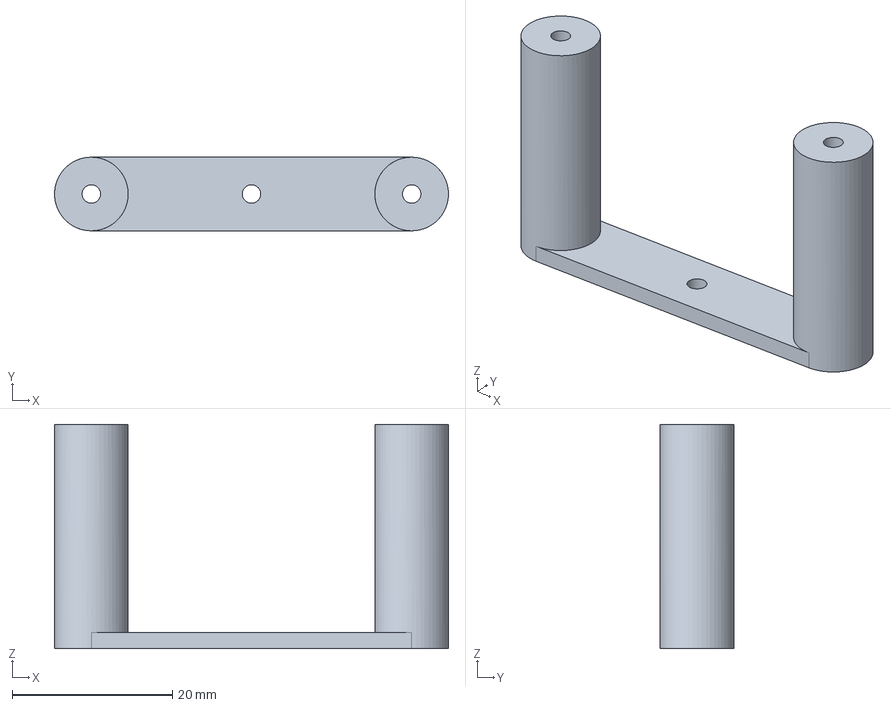
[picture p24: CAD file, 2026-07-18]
freecad/PcbFrontBrace.FCStd
49.2 x 9.20 x 28.0 mm

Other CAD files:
freecad/NewAssembly.FCStd
production/printed/kabot_11x_17h_380g.gcode.3mf
freecad/PcbBackBrace.FCStd
production/printed/kabot_base_4x_3h_100g.gcode.3mf
freecad/Wheel/Wheel.FCStd
freecad/N20/N20.FCStd
freecad/Battery.FCStd

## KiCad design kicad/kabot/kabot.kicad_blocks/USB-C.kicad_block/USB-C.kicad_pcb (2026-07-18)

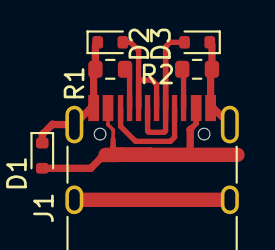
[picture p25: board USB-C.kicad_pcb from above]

Board: 2 copper layers, 6 parts (0 on the bottom side), 7 nets.

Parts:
D1, D2, D3: LESD5D5; D_SOD-523
J1: USB_C_Receptacle_USB2.0; USB_C_Receptacle_HRO_TYPE-C-31-M-12
R1, R2: 5k1; R_0603_1608Metric

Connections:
+5VD: D1.2 (A2), J1.A4 (VBUS), J1.A9 (VBUS), J1.B4 (VBUS), J1.B9 (VBUS)
/USB_D+: D3.2 (A2), J1.A6 (D+), J1.B6 (D+)
/USB_D-: D2.2 (A2), J1.A7 (D-), J1.B7 (D-)
GND: D1.1 (A1), D2.1 (A1), D3.1 (A1), J1.A1 (GND), J1.A12 (GND), J1.B1 (GND), J1.B12 (GND), J1.S1 (SHIELD), R1.2, R2.2
unnamed: J1.A5 (CC1), R1.1
unnamed: J1.B5 (CC2), R2.1
unnamed: J1.A8 (SBU1), J1.B8 (SBU2)

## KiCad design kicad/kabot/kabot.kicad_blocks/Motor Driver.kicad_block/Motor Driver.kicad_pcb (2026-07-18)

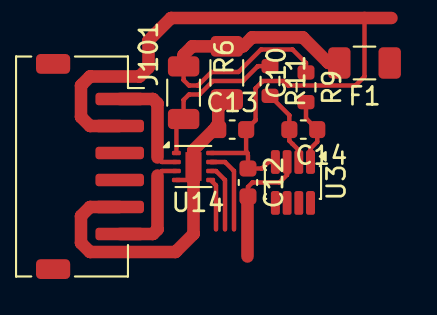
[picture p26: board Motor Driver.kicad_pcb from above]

Board: 2 copper layers, 11 parts (0 on the bottom side), 8 nets.

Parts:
C10: 22u; C_1206_3216Metric
C12, C13, C14: 100n; C_0603_1608Metric
F1: 1.8A; Fuse_1206_3216Metric
J101: Conn_01x06_MountingPin; JST_ZH_S6B-ZR-SM4A-TF_1x06-1MP_P1.50mm_Horizontal
R6: 0R1; R_1206_3216Metric
R9, R11: 1R; R_0603_1608Metric
U3: INA219AxDCN; SOT-23-8
U14: DRV8837; WSON-8-1EP_2x2mm_P0.5mm_EP0.9x1.6mm

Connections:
/Motor Driver/3V3: C12.1, C13.1, J101.2, U3.4 (VS), U14.8 (VCC)
/Motor Driver/GND: C10.2, C12.2, C13.2, J101.5, U3.3 (GND), U14.4 (GND), U14.9 (GND)
unnamed: C10.1, F1.2, R6.1, R9.1
unnamed: J101.1, U14.2 (OUT1)
unnamed: J101.6, U14.3 (OUT2)
unnamed: C14.1, R9.2, U3.1 (IN+)
unnamed: C14.2, R11.2, U3.2 (IN-)
unnamed: R6.2, R11.1, U14.1 (VM)

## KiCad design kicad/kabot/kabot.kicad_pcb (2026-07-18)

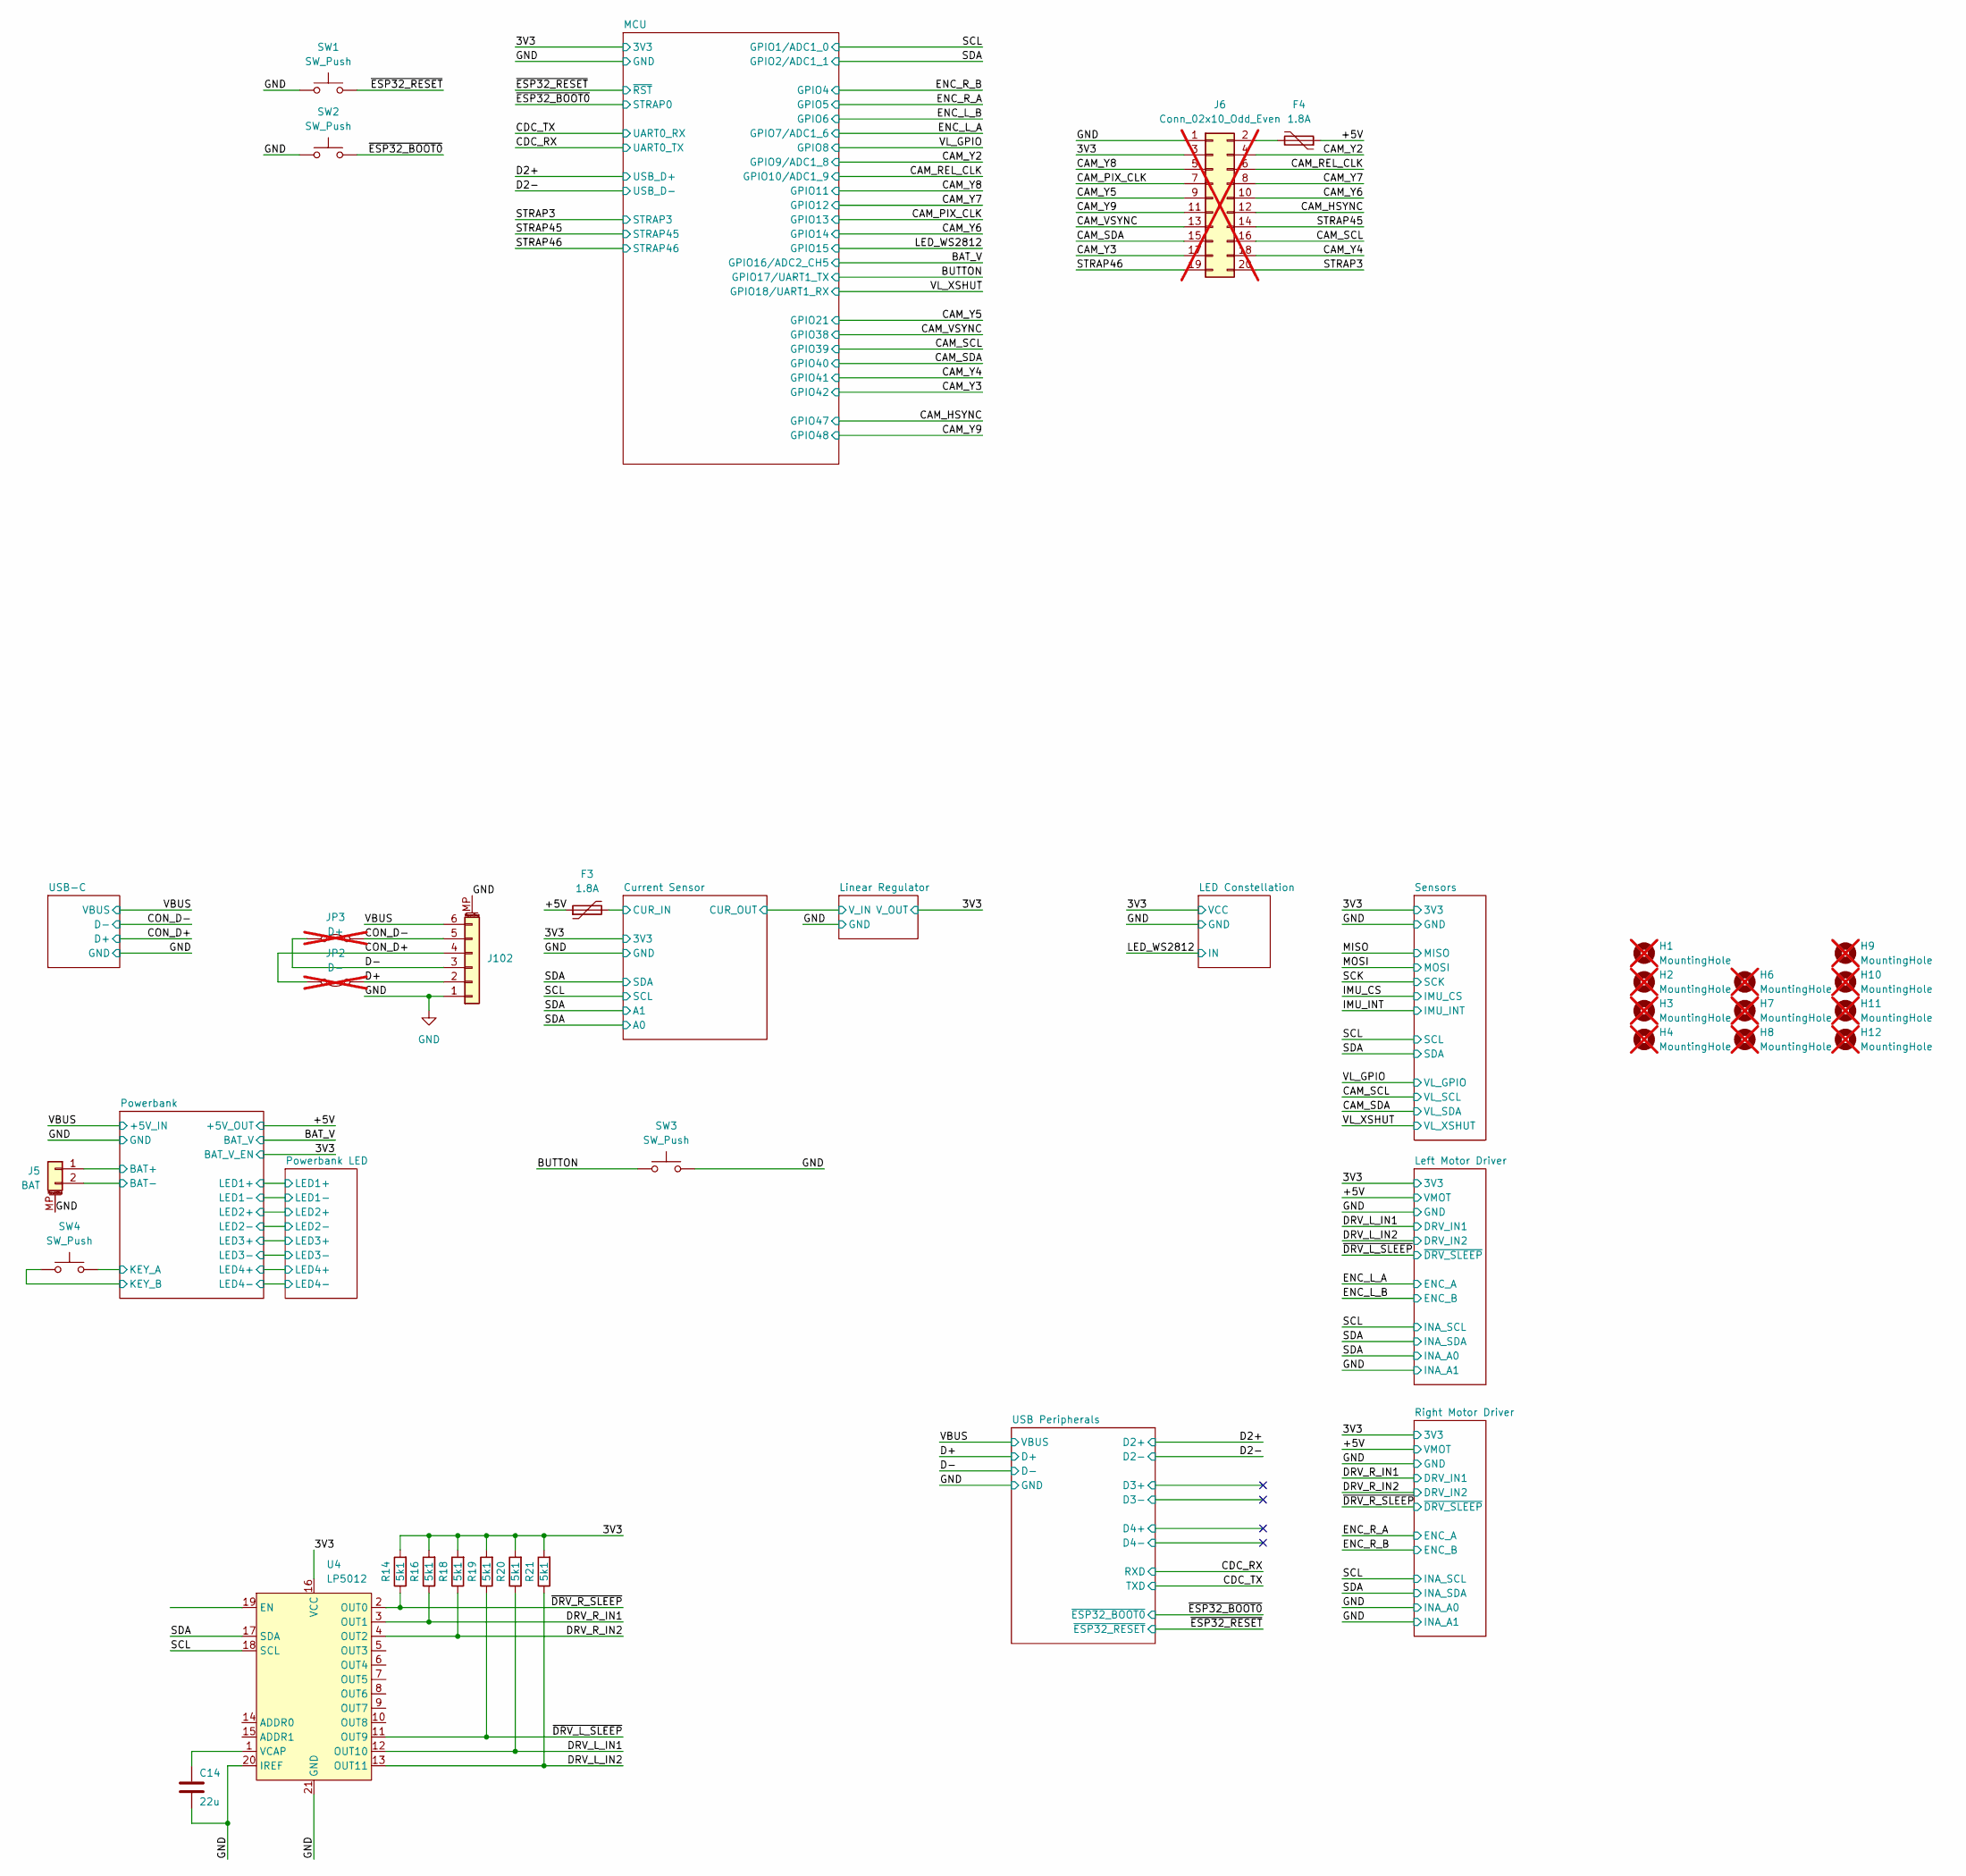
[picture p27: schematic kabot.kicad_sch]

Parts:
C14: 22u; C_1206_3216Metric; JLC C12891
F3, F4: 1.8A; Fuse_1206_3216Metric; JLC C5375706
H1, H2, H3, H4, H6, H7, H8, H9, H10, H11, H12: MountingHole; MountingHole_3.5mm; not fitted
J5: BAT; JST_ZH_S2B-ZR-SM4A-TF_1x02-1MP_P1.50mm_Horizontal
J6: Conn_02x10_Odd_Even; PinSocket_2x10_P2.54mm_Vertical; not fitted
J102: Conn_01x06_MountingPin; JST_ZH_S6B-ZR-SM4A-TF_1x06-1MP_P1.50mm_Horizontal
JP2: D-; SolderJumper-2_P1.3mm_Bridged_RoundedPad1.0x1.5mm; not fitted
JP3: D+; SolderJumper-2_P1.3mm_Bridged_RoundedPad1.0x1.5mm; not fitted
R14, R16, R18, R19, R20, R21: 5k1; R_0603_1608Metric; JLC C23186
SW1, SW2, SW3, SW4: SW_Push; SW_Push_SPST_NO_Alps_SKRK
U4: LP5012; WQFN-20-1EP_3x3mm_P0.4mm_EP1.7x1.7mm; JLC C1849481

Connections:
/3V3: J6.3, R14.2, R16.2, R18.2, R19.2, R20.2, R21.2, U4.16 (VCC); also elsewhere on the board
/+5V: F3.1, F4.1; also elsewhere on the board
/BUTTON: SW3.1; also elsewhere on the board
/CAM_HSYNC: J6.12; also elsewhere on the board
/CAM_PIX_CLK: J6.7; also elsewhere on the board
/CAM_REL_CLK: J6.6; also elsewhere on the board
/CAM_SCL: J6.16; also elsewhere on the board
/CAM_SDA: J6.15; also elsewhere on the board
/CAM_VSYNC: J6.13; also elsewhere on the board
/CAM_Y2: J6.4; also elsewhere on the board
/CAM_Y3: J6.17; also elsewhere on the board
/CAM_Y4: J6.18; also elsewhere on the board
/CAM_Y5: J6.9; also elsewhere on the board
/CAM_Y6: J6.10; also elsewhere on the board
/CAM_Y7: J6.8; also elsewhere on the board
/CAM_Y8: J6.5; also elsewhere on the board
/CAM_Y9: J6.11; also elsewhere on the board
/CON_D+: J102.4, JP2.2 (B); also elsewhere on the board
/CON_D-: J102.5, JP3.1 (A); also elsewhere on the board
/Current Sensor/CUR_IN: F3.2; also elsewhere on the board
/D+: J102.2, JP2.1 (A); also elsewhere on the board
/D-: J102.3, JP3.2 (B); also elsewhere on the board
/DRV_L_IN1: R20.1, U4.12 (OUT10); also elsewhere on the board
/DRV_L_IN2: R21.1, U4.13 (OUT11); also elsewhere on the board
/DRV_R_IN1: R16.1, U4.3 (OUT1); also elsewhere on the board
/DRV_R_IN2: R18.1, U4.4 (OUT2); also elsewhere on the board
/Powerbank/BAT+: J5.1; also elsewhere on the board
/Powerbank/KEY_A: SW4.2; also elsewhere on the board
/SCL: U4.18 (SCL); also elsewhere on the board
/SDA: U4.17 (SDA); also elsewhere on the board
/STRAP3: J6.20; also elsewhere on the board
/STRAP45: J6.14; also elsewhere on the board
/STRAP46: J6.19; also elsewhere on the board
/VBUS: J102.6; also elsewhere on the board
/~DRV_L_SLEEP: R19.1, U4.11 (OUT9); also elsewhere on the board
/~DRV_R_SLEEP: R14.1, U4.2 (OUT0); also elsewhere on the board
/~ESP32_BOOT0: SW2.1; also elsewhere on the board
/~ESP32_RESET: SW1.2; also elsewhere on the board
GND: C14.2, J5.2, J5.MP (MountPin), J6.1, J102.1, J102.MP (MountPin), SW1.1, SW2.2, SW3.2, SW4.1, U4.20 (IREF), U4.21 (GND); also elsewhere on the board
unnamed: F4.2, J6.2
unnamed: C14.1, U4.1 (VCAP)

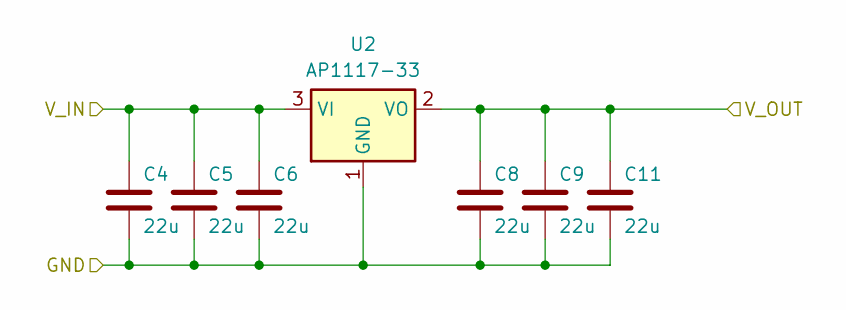
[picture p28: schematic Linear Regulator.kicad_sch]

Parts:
C4, C5, C6, C8, C9, C11: 22u; C_1206_3216Metric; JLC C12891
U2: AP1117-33; SOT-223-3_TabPin2; JLC C6186

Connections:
/3V3: C8.1, C9.1, C11.1, U2.2 (VO); also elsewhere on the board
/Current Sensor/CUR_OUT: C4.1, C5.1, C6.1, U2.3 (VI); also elsewhere on the board
GND: C4.2, C5.2, C6.2, C8.2, C9.2, C11.2, U2.1 (GND); also elsewhere on the board

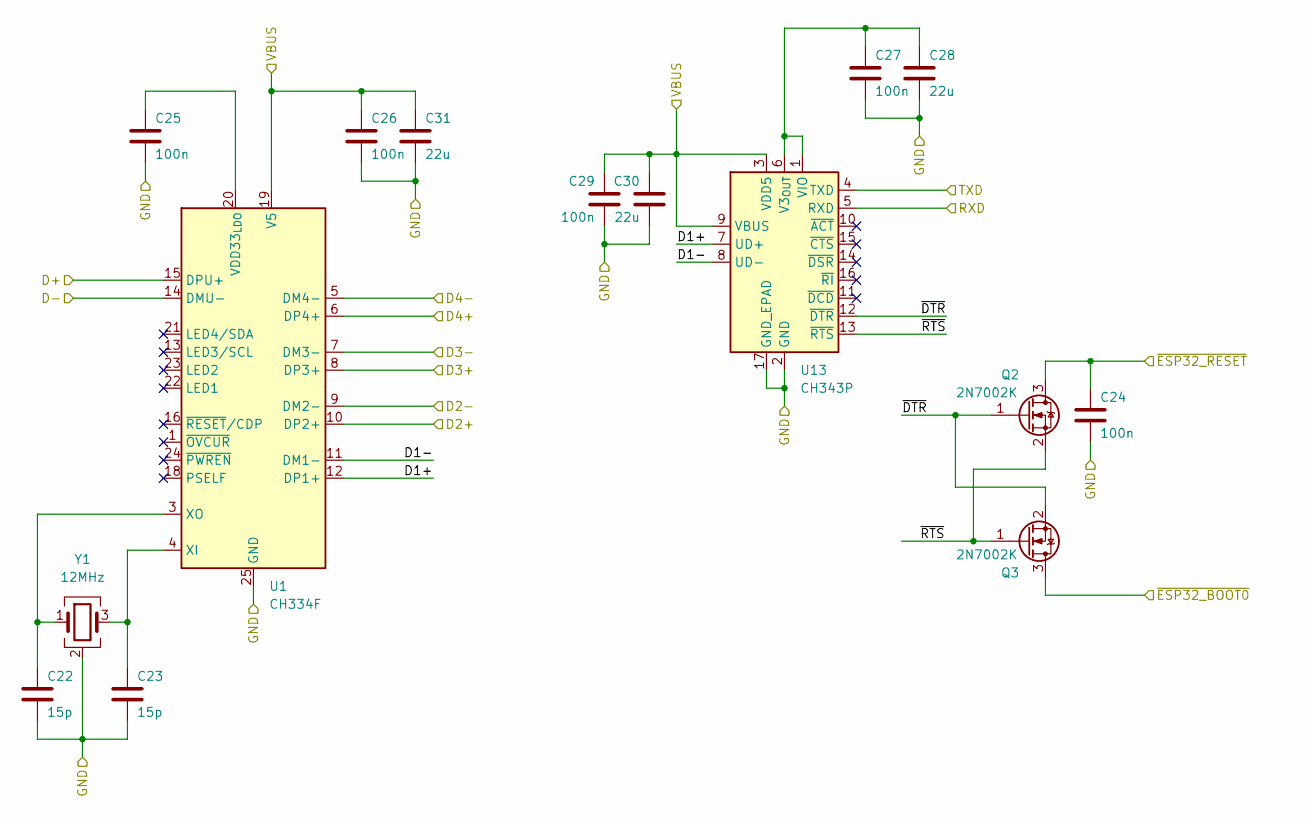
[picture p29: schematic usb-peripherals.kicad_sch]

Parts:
C22, C23: 15p; C_0603_1608Metric; JLC C1644
C24, C25, C26, C27, C29: 100n; C_0603_1608Metric; JLC C14663
C28, C30, C31: 22u; C_1206_3216Metric; JLC C12891
Q2, Q3: 2N7002K; SOT-23; JLC C8545
U1: CH334F; QFN-24-1EP_4x4mm_P0.5mm_EP2.7x2.7mm; JLC C5187527
U13: CH343P; WCH_QFN-16-1EP_3x3mm_P0.5mm_EP1.8x1.8mm
Y1: 12MHz; Crystal_SMD_3225-4Pin_3.2x2.5mm; JLC C9002

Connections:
/CDC_RX: U13.5 (RXD); also elsewhere on the board
/CDC_TX: U13.4 (TXD); also elsewhere on the board
/D2+: U1.10 (DP2+); also elsewhere on the board
/D2-: U1.9 (DM2-); also elsewhere on the board
/D+: U1.15 (DPU+); also elsewhere on the board
/D-: U1.14 (DMU-); also elsewhere on the board
/USB Peripherals/D1+: U1.12 (DP1+), U13.7 (UD+)
/USB Peripherals/D1-: U1.11 (DM1-), U13.8 (UD-)
/USB Peripherals/D3+: U1.8 (DP3+)
/USB Peripherals/D3-: U1.7 (DM3-)
/USB Peripherals/D4+: U1.6 (DP4+)
/USB Peripherals/D4-: U1.5 (DM4-)
/USB Peripherals/~DTR: Q2.1 (G), Q3.2 (S), U13.12 (~DTR)
/USB Peripherals/~RTS: Q2.2 (S), Q3.1 (G), U13.13 (~RTS)
/VBUS: C26.1, C29.1, C30.1, C31.1, U1.19 (V5), U13.3 (VDD5), U13.9 (VBUS); also elsewhere on the board
/~ESP32_BOOT0: Q3.3 (D); also elsewhere on the board
/~ESP32_RESET: C24.1, Q2.3 (D); also elsewhere on the board
GND: C22.2, C23.2, C24.2, C25.2, C26.2, C27.2, C28.2, C29.2, C30.2, C31.2, U1.25 (GND), U13.2 (GND), U13.17 (GND_EPAD), Y1.2 (G), Y1.4 (G); also elsewhere on the board
unnamed: C25.1, U1.20 (VDD33_{LDO})
unnamed: C23.1, U1.4 (XI), Y1.3
unnamed: C22.1, U1.3 (XO), Y1.1
unnamed: C27.1, C28.1, U13.1 (VIO), U13.6 (V3_{OUT})

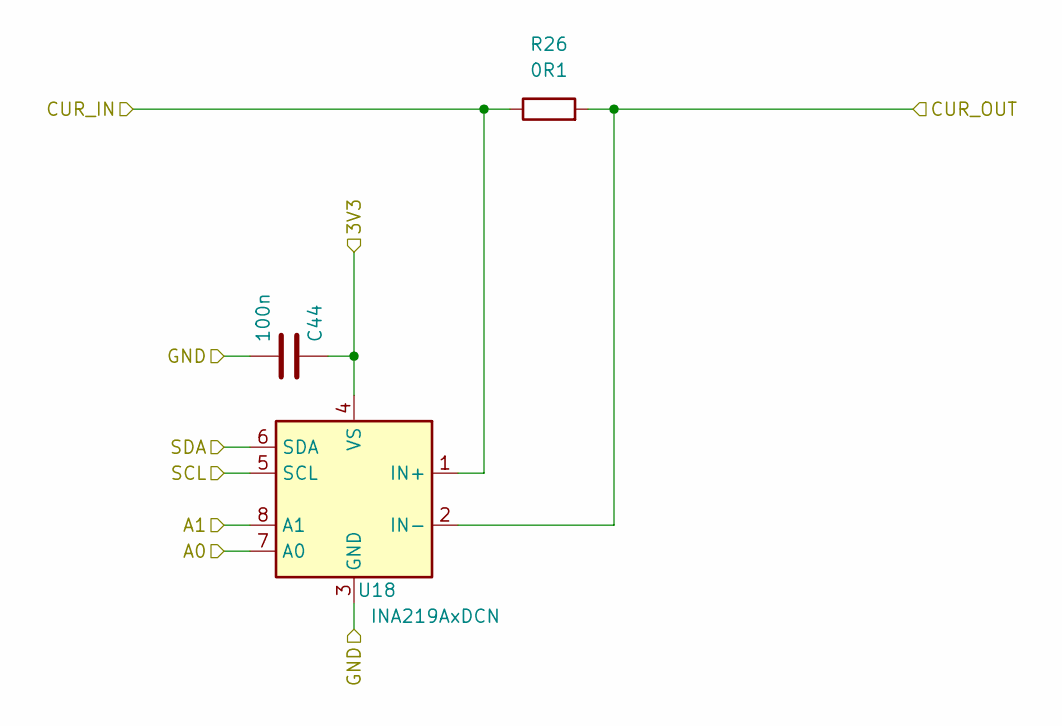
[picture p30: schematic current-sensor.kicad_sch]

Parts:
C44: 100n; C_0603_1608Metric; JLC C14663
R26: 0R1; R_1206_3216Metric; JLC C25334
U18: INA219AxDCN; SOT-23-8

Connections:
/3V3: C44.1, U18.4 (VS); also elsewhere on the board
/Current Sensor/CUR_IN: R26.1, U18.1 (IN+); also elsewhere on the board
/Current Sensor/CUR_OUT: R26.2, U18.2 (IN-); also elsewhere on the board
/SCL: U18.5 (SCL); also elsewhere on the board
/SDA: U18.6 (SDA), U18.7 (A0), U18.8 (A1); also elsewhere on the board
GND: C44.2, U18.3 (GND); also elsewhere on the board

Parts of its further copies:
C38, C42: 100n; C_0603_1608Metric; JLC C14663
R17, R23: 0R1; R_1206_3216Metric; JLC C25334
U9, U17: INA219AxDCN; SOT-23-8

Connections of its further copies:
/3V3: C38.1, C42.1, U9.4 (VS), U17.4 (VS); also elsewhere on the board
/Left Motor Driver/Current Sensor/CUR_IN: R23.1, U17.1 (IN+); also elsewhere on the board
/Left Motor Driver/Current Sensor/CUR_OUT: R23.2, U17.2 (IN-); also elsewhere on the board
/Right Motor Driver/Current Sensor/CUR_IN: R17.1, U9.1 (IN+); also elsewhere on the board
/Right Motor Driver/Current Sensor/CUR_OUT: R17.2, U9.2 (IN-); also elsewhere on the board
/SCL: U9.5 (SCL), U17.5 (SCL); also elsewhere on the board
/SDA: U9.6 (SDA), U17.6 (SDA), U17.7 (A0); also elsewhere on the board
GND: C38.2, C42.2, U9.3 (GND), U9.7 (A0), U9.8 (A1), U17.3 (GND), U17.8 (A1); also elsewhere on the board

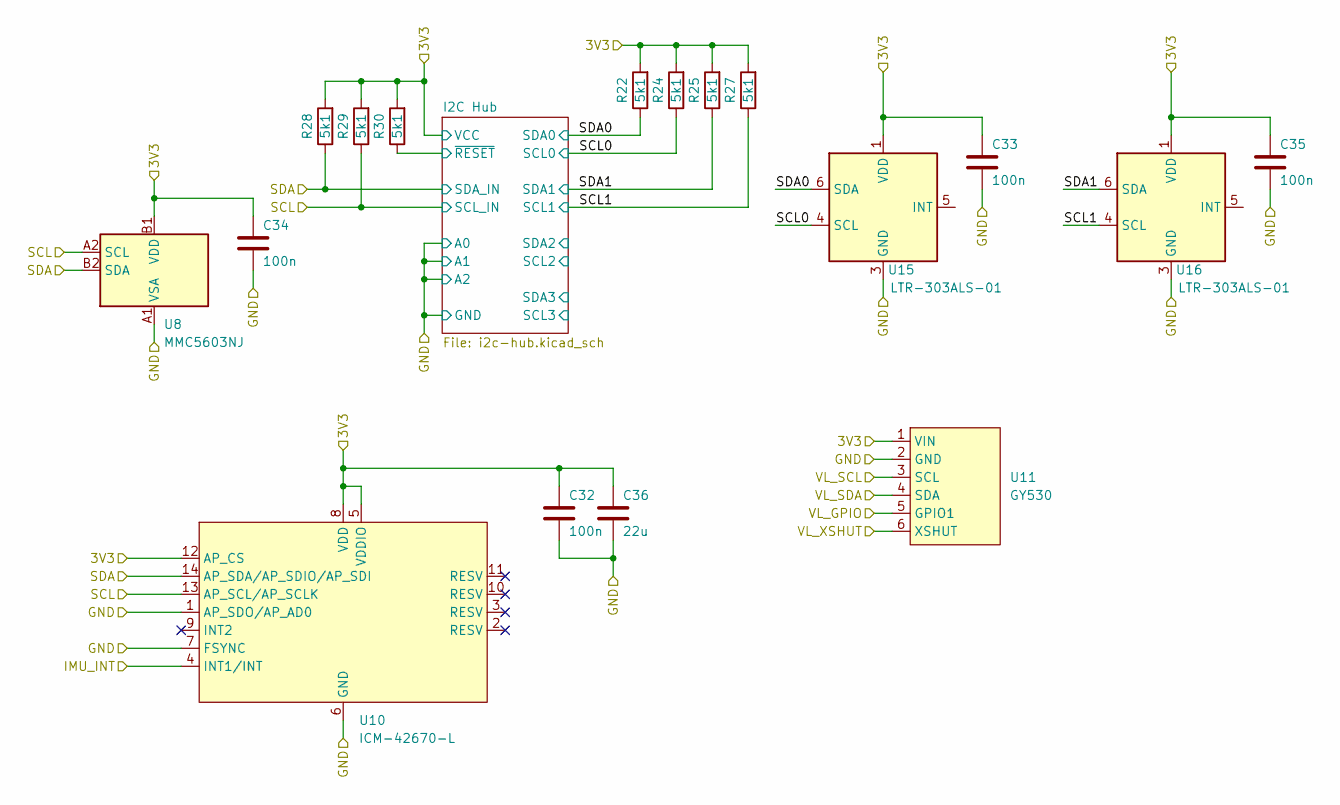
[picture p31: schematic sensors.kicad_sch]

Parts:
C32, C33, C34, C35: 100n; C_0603_1608Metric; JLC C14663
C36: 22u; C_1206_3216Metric; JLC C12891
R22, R24, R25, R27, R28, R29, R30: 5k1; R_0603_1608Metric; JLC C23186
U8: MMC5603NJ; WLP-4_0.86x0.86mm_P0.4mm; JLC C404328
U10: ICM-42670-L; LGA-14_3x2.5mm_P0.5mm_LayoutBorder3x4y; JLC C49073546
U11: GY530
U15, U16: LTR-303ALS-01; Lite-On_LTR-303ALS-01; JLC C364577

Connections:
/3V3: C32.1, C33.1, C34.1, C35.1, C36.1, R22.2, R24.2, R25.2, R27.2, R28.2, R29.2, R30.2, U8.B1 (VDD), U10.5 (VDDIO), U10.8 (VDD), U10.12 (AP_CS), U11.1 (VIN), U15.1 (VDD), U16.1 (VDD); also elsewhere on the board
/CAM_SCL: U11.3 (SCL); also elsewhere on the board
/CAM_SDA: U11.4 (SDA); also elsewhere on the board
/IMU_INT: U10.4 (INT1/INT)
/SCL: R29.1, U8.A2 (SCL), U10.13 (AP_SCL/AP_SCLK); also elsewhere on the board
/SDA: R28.1, U8.B2 (SDA), U10.14 (AP_SDA/AP_SDIO/AP_SDI); also elsewhere on the board
/Sensors/I2C Hub/~RESET: R30.1; also elsewhere on the board
/Sensors/SCL0: R24.1, U15.4 (SCL); also elsewhere on the board
/Sensors/SCL1: R27.1, U16.4 (SCL); also elsewhere on the board
/Sensors/SDA0: R22.1, U15.6 (SDA); also elsewhere on the board
/Sensors/SDA1: R25.1, U16.6 (SDA); also elsewhere on the board
/VL_GPIO: U11.5 (GPIO1); also elsewhere on the board
/VL_XSHUT: U11.6 (XSHUT); also elsewhere on the board
GND: C32.2, C33.2, C34.2, C35.2, C36.2, U8.A1 (VSA), U10.1 (AP_SDO/AP_AD0), U10.6 (GND), U10.7 (FSYNC), U11.2 (GND), U15.3 (GND), U16.3 (GND); also elsewhere on the board

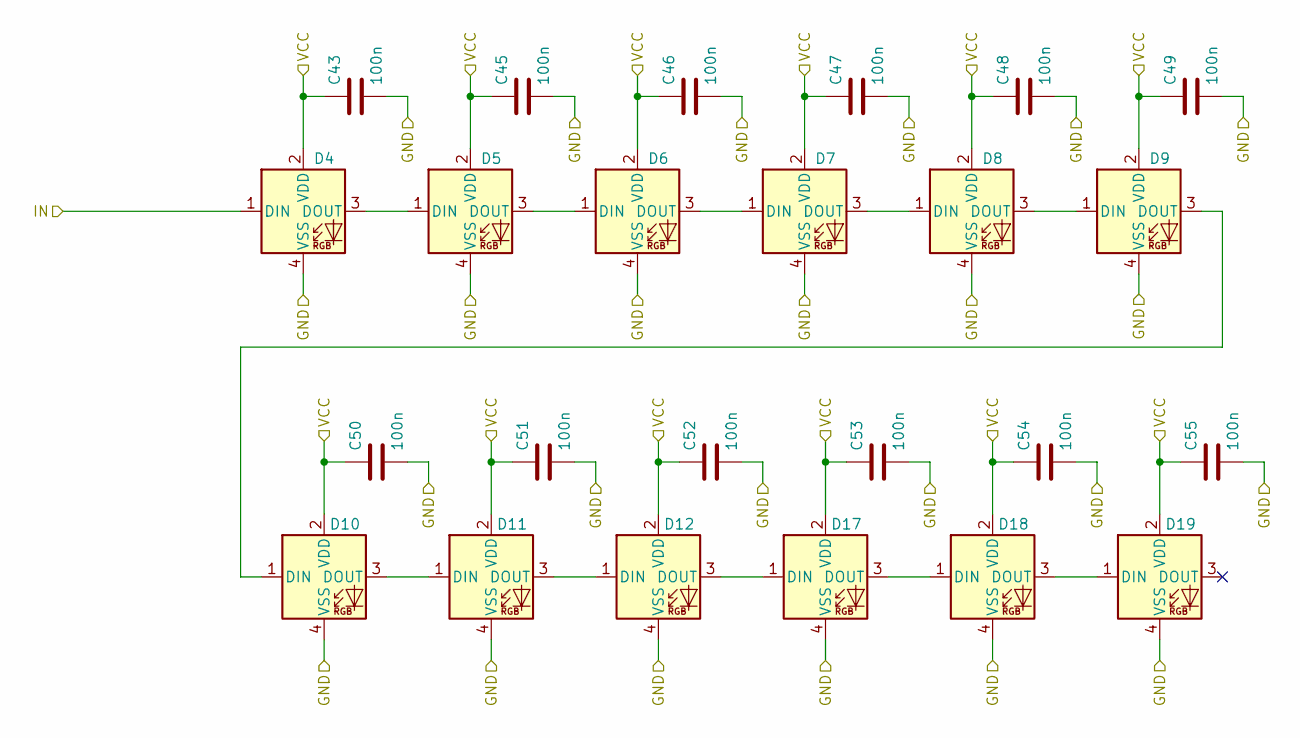
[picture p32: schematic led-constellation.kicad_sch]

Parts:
C43, C45, C46, C47, C48, C49, C50, C51, C52, C53, C54, C55: 100n; C_0603_1608Metric; JLC C14663
D4, D5, D6, D7, D8, D9, D10, D11, D12, D17, D18, D19: XL2121RGBC-WS2812B; LED_ASMB-KTF0-0A306; JLC C5349957

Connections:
/3V3: C43.1, C45.1, C46.1, C47.1, C48.1, C49.1, C50.1, C51.1, C52.1, C53.1, C54.1, C55.1, D4.2 (VDD), D5.2 (VDD), D6.2 (VDD), D7.2 (VDD), D8.2 (VDD), D9.2 (VDD), D10.2 (VDD), D11.2 (VDD), D12.2 (VDD), D17.2 (VDD), D18.2 (VDD), D19.2 (VDD); also elsewhere on the board
/LED_WS2812: D4.1 (DIN); also elsewhere on the board
GND: C43.2, C45.2, C46.2, C47.2, C48.2, C49.2, C50.2, C51.2, C52.2, C53.2, C54.2, C55.2, D4.4 (VSS), D5.4 (VSS), D6.4 (VSS), D7.4 (VSS), D8.4 (VSS), D9.4 (VSS), D10.4 (VSS), D11.4 (VSS), D12.4 (VSS), D17.4 (VSS), D18.4 (VSS), D19.4 (VSS); also elsewhere on the board
unnamed: D4.3 (DOUT), D5.1 (DIN)
unnamed: D5.3 (DOUT), D6.1 (DIN)
unnamed: D6.3 (DOUT), D7.1 (DIN)
unnamed: D7.3 (DOUT), D8.1 (DIN)
unnamed: D8.3 (DOUT), D9.1 (DIN)
unnamed: D9.3 (DOUT), D10.1 (DIN)
unnamed: D10.3 (DOUT), D11.1 (DIN)
unnamed: D11.3 (DOUT), D12.1 (DIN)
unnamed: D12.3 (DOUT), D17.1 (DIN)
unnamed: D17.3 (DOUT), D18.1 (DIN)
unnamed: D18.3 (DOUT), D19.1 (DIN)

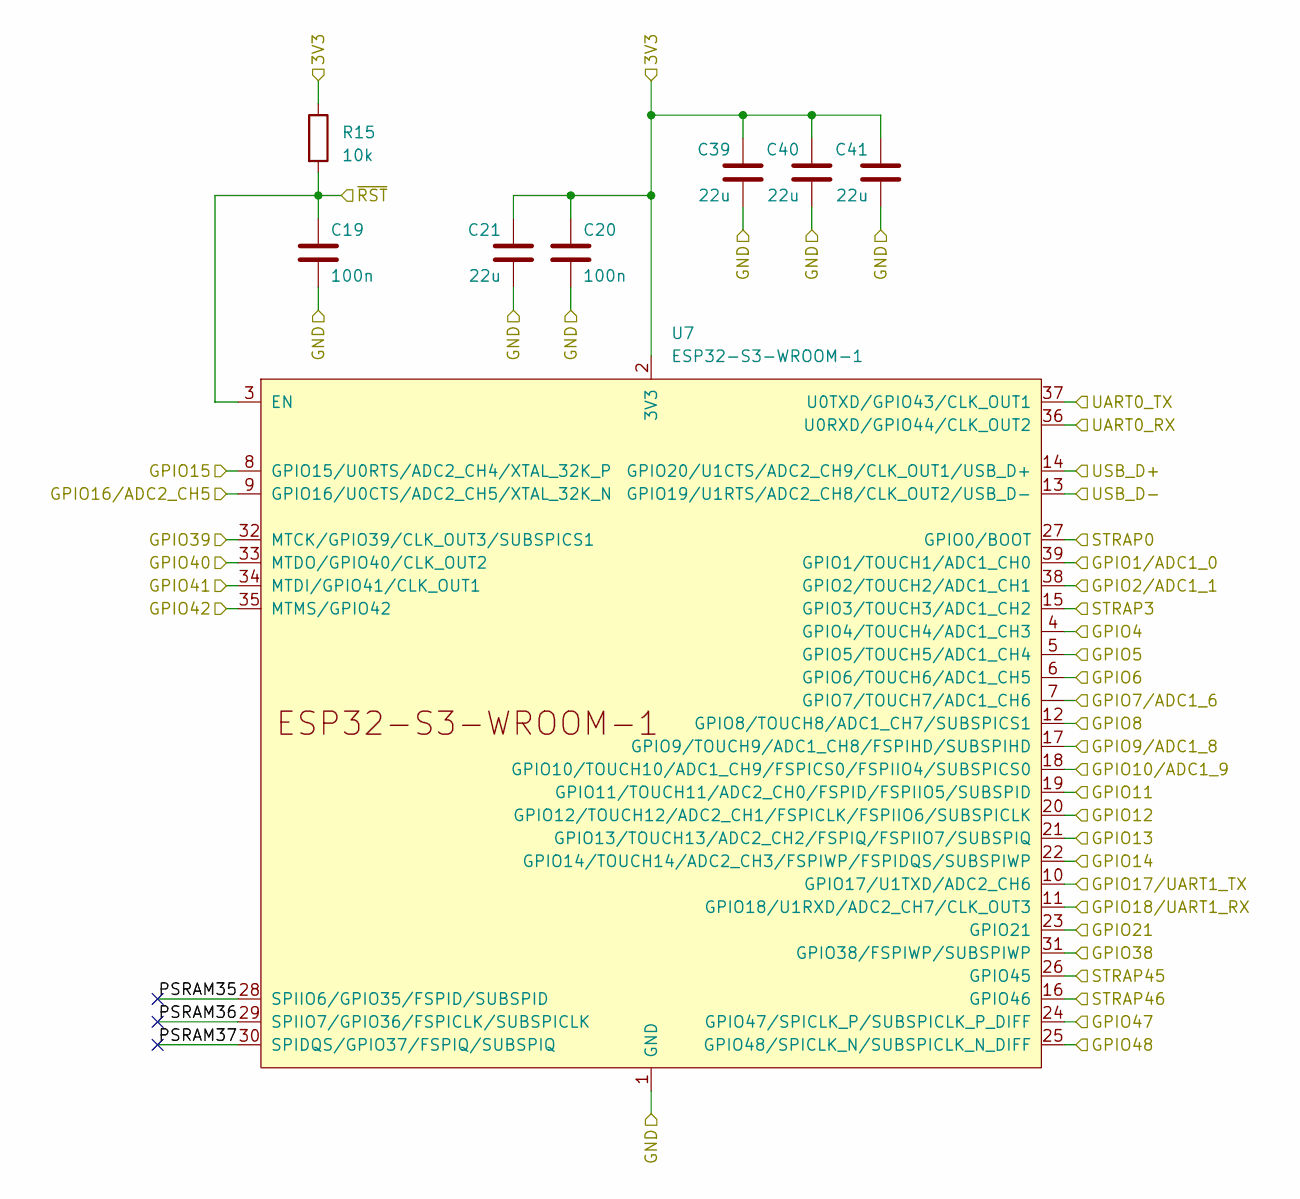
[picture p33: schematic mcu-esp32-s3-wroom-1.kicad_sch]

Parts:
C19, C20: 100n; C_0603_1608Metric; JLC C14663
C21, C39, C40, C41: 22u; C_1206_3216Metric; JLC C12891
R15: 10k; R_0603_1608Metric; JLC C25804
U7: ESP32-S3-WROOM-1

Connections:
/3V3: C20.1, C21.1, C39.1, C40.1, C41.1, R15.1, U7.2 (3V3); also elsewhere on the board
/BAT_V: U7.9 (GPIO16/U0CTS/ADC2_CH5/XTAL_32K_N); also elsewhere on the board
/BUTTON: U7.10 (GPIO17/U1TXD/ADC2_CH6); also elsewhere on the board
/CAM_HSYNC: U7.24 (GPIO47/SPICLK_P/SUBSPICLK_P_DIFF); also elsewhere on the board
/CAM_PIX_CLK: U7.21 (GPIO13/TOUCH13/ADC2_CH2/FSPIQ/FSPIIO7/S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); also elsewhere on the board
/CAM_REL_CLK: U7.18 (GPIO10/TOUCH10/ADC1_CH9/FSPICS0/FSPIIO4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); also elsewhere on the board
/CAM_SCL: U7.32 (MTCK/GPIO39/CLK_OUT3/SUBSPICS1); also elsewhere on the board
/CAM_SDA: U7.33 (MTDO/GPIO40/CLK_OUT2); also elsewhere on the board
/CAM_VSYNC: U7.31 (GPIO38/FSPIWP/SUBSPIWP); also elsewhere on the board
/CAM_Y2: U7.17 (GPIO9/TOUCH9/ADC1_CH8/FSPIHD/SUBSPIHD); also elsewhere on the board
/CAM_Y3: U7.35 (MTMS/GPIO42); also elsewhere on the board
/CAM_Y4: U7.34 (MTDI/GPIO41/CLK_OUT1); also elsewhere on the board
/CAM_Y5: U7.23 (GPIO21); also elsewhere on the board
/CAM_Y6: U7.22 (GPIO14/TOUCH14/ADC2_CH3/FSPIWP/FSPIDQS/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); also elsewhere on the board
/CAM_Y7: U7.20 (GPIO12/TOUCH12/ADC2_CH1/FSPICLK/FSPIIO6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); also elsewhere on the board
/CAM_Y8: U7.19 (GPIO11/TOUCH11/ADC2_CH0/FSPID/FSPIIO5/S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); also elsewhere on the board
/CAM_Y9: U7.25 (GPIO48/SPICLK_N/SUBSPICLK_N_DIFF); also elsewhere on the board
/CDC_RX: U7.37 (U0TXD/GPIO43/CLK_OUT1); also elsewhere on the board
/CDC_TX: U7.36 (U0RXD/GPIO44/CLK_OUT2); also elsewhere on the board
/D2+: U7.14 (GPIO20/U1CTS/ADC2_CH9/CLK_OUT1/USB_D+); also elsewhere on the board
/D2-: U7.13 (GPIO19/U1RTS/ADC2_CH8/CLK_OUT2/USB_D-); also elsewhere on the board
/ENC_L_A: U7.7 (GPIO7/TOUCH7/ADC1_CH6); also elsewhere on the board
/ENC_L_B: U7.6 (GPIO6/TOUCH6/ADC1_CH5); also elsewhere on the board
/ENC_R_A: U7.5 (GPIO5/TOUCH5/ADC1_CH4); also elsewhere on the board
/ENC_R_B: U7.4 (GPIO4/TOUCH4/ADC1_CH3); also elsewhere on the board
/LED_WS2812: U7.8 (GPIO15/U0RTS/ADC2_CH4/XTAL_32K_P); also elsewhere on the board
/MCU/PSRAM35: U7.28 (SPIIO6/GPIO35/FSPID/SUBSPID)
/MCU/PSRAM36: U7.29 (SPIIO7/GPIO36/FSPICLK/SUBSPICLK)
/MCU/PSRAM37: U7.30 (SPIDQS/GPIO37/FSPIQ/SUBSPIQ)
/SCL: U7.39 (GPIO1/TOUCH1/ADC1_CH0); also elsewhere on the board
/SDA: U7.38 (GPIO2/TOUCH2/ADC1_CH1); also elsewhere on the board
/STRAP3: U7.15 (GPIO3/TOUCH3/ADC1_CH2); also elsewhere on the board
/STRAP45: U7.26 (GPIO45); also elsewhere on the board
/STRAP46: U7.16 (GPIO46); also elsewhere on the board
/VL_GPIO: U7.12 (GPIO8/TOUCH8/ADC1_CH7/SUBSPICS1); also elsewhere on the board
/VL_XSHUT: U7.11 (GPIO18/U1RXD/ADC2_CH7/CLK_OUT3); also elsewhere on the board
/~ESP32_BOOT0: U7.27 (GPIO0/BOOT); also elsewhere on the board
/~ESP32_RESET: C19.1, R15.2, U7.3 (EN); also elsewhere on the board
GND: C19.2, C20.2, C21.2, C39.2, C40.2, C41.2, U7.1 (GND), U7.40 (GND), U7.41 (GND); also elsewhere on the board

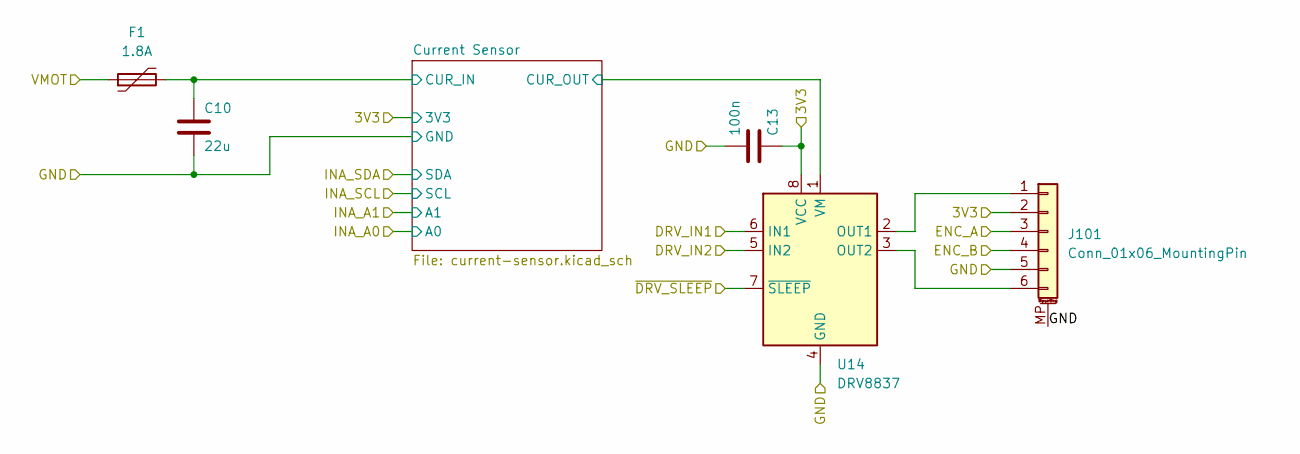
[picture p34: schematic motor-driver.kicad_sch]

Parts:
C10: 22u; C_1206_3216Metric; JLC C12891
C13: 100n; C_0603_1608Metric; JLC C14663
F1: 1.8A; Fuse_1206_3216Metric; JLC C5375706
J101: Conn_01x06_MountingPin; JST_ZH_S6B-ZR-SM4A-TF_1x06-1MP_P1.50mm_Horizontal
U14: DRV8837; WSON-8-1EP_2x2mm_P0.5mm_EP0.9x1.6mm; JLC C39159

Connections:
/3V3: C13.1, J101.2, U14.8 (VCC); also elsewhere on the board
/+5V: F1.1; also elsewhere on the board
/DRV_L_IN1: U14.6 (IN1); also elsewhere on the board
/DRV_L_IN2: U14.5 (IN2); also elsewhere on the board
/ENC_L_A: J101.3; also elsewhere on the board
/ENC_L_B: J101.4; also elsewhere on the board
/Left Motor Driver/Current Sensor/CUR_IN: C10.1, F1.2; also elsewhere on the board
/Left Motor Driver/Current Sensor/CUR_OUT: U14.1 (VM); also elsewhere on the board
/~DRV_L_SLEEP: U14.7 (~SLEEP); also elsewhere on the board
GND: C10.2, C13.2, J101.5, J101.MP (MountPin), U14.4 (GND), U14.9 (GND); also elsewhere on the board
unnamed: J101.1, U14.2 (OUT1)
unnamed: J101.6, U14.3 (OUT2)

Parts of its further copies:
C12: 22u; C_1206_3216Metric; JLC C12891
C18: 100n; C_0603_1608Metric; JLC C14663
F2: 1.8A; Fuse_1206_3216Metric; JLC C5375706
J1: Conn_01x06_MountingPin; JST_ZH_S6B-ZR-SM4A-TF_1x06-1MP_P1.50mm_Horizontal
U6: DRV8837; WSON-8-1EP_2x2mm_P0.5mm_EP0.9x1.6mm; JLC C39159

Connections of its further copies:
/3V3: C18.1, J1.2, U6.8 (VCC); also elsewhere on the board
/+5V: F2.1; also elsewhere on the board
/DRV_R_IN1: U6.6 (IN1); also elsewhere on the board
/DRV_R_IN2: U6.5 (IN2); also elsewhere on the board
/ENC_R_A: J1.3; also elsewhere on the board
/ENC_R_B: J1.4; also elsewhere on the board
/Right Motor Driver/Current Sensor/CUR_IN: C12.1, F2.2; also elsewhere on the board
/Right Motor Driver/Current Sensor/CUR_OUT: U6.1 (VM); also elsewhere on the board
/~DRV_R_SLEEP: U6.7 (~SLEEP); also elsewhere on the board
GND: C12.2, C18.2, J1.5, J1.MP (MountPin), U6.4 (GND), U6.9 (GND); also elsewhere on the board
unnamed: J1.1, U6.2 (OUT1)
unnamed: J1.6, U6.3 (OUT2)

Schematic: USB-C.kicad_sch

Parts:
D1, D2, D3: LESD5D5; D_SOD-523; JLC C383211
J8: USB_C_Receptacle_USB2.0_16P; USB_C_Receptacle_GCT_USB4105-xx-A_16P_TopMnt_Horizontal
R1, R2: 5k1; R_0603_1608Metric; JLC C23186

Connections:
/CON_D+: D3.2 (A2), J8.A6 (D+), J8.B6 (D+); also elsewhere on the board
/CON_D-: D2.2 (A2), J8.A7 (D-), J8.B7 (D-); also elsewhere on the board
/VBUS: D1.2 (A2), J8.A4 (VBUS), J8.A9 (VBUS), J8.B4 (VBUS), J8.B9 (VBUS); also elsewhere on the board
GND: D1.1 (A1), D2.1 (A1), D3.1 (A1), J8.A1 (GND), J8.A12 (GND), J8.B1 (GND), J8.B12 (GND), J8.SH (SHIELD), R1.2, R2.2; also elsewhere on the board
unnamed: J8.A5 (CC1), R1.1
unnamed: J8.B5 (CC2), R2.1

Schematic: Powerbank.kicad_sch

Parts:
C1, C2, C7: 22u; C_1206_3216Metric; JLC C12891
L1: 1u; L_Changjiang_FNR5045S; JLC C436396
Q1: 2N7002K; SOT-23; JLC C8545
R3, R4: 1R; R_0603_1608Metric; JLC C22936
R5, R8, R10: 10k; R_0603_1608Metric; JLC C25804
R7: 5k1; R_0603_1608Metric; JLC C23186
U5: IP5306; Diodes_SO-8EP; JLC C181692

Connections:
/3V3: Q1.1 (G), R10.1; also elsewhere on the board
/+5V: U5.8 (VOUT); also elsewhere on the board
/BAT_V: R7.1, R8.1; also elsewhere on the board
/Powerbank LED/LED1+: U5.2 (LED1); also elsewhere on the board
/Powerbank LED/LED1-: U5.4 (LED3); also elsewhere on the board
/Powerbank LED/LED3+: U5.3 (LED2); also elsewhere on the board
/Powerbank/BAT+: C2.1, L1.2, R3.1, R7.2; also elsewhere on the board
/Powerbank/KEY_A: R5.2; also elsewhere on the board
/VBUS: R4.1, U5.1 (VIN); also elsewhere on the board
GND: C1.2, C2.2, C7.2, Q1.2 (S), R10.2, U5.9 (GND); also elsewhere on the board
unnamed: C7.1, R4.2
unnamed: Q1.3 (D), R8.2
unnamed: C1.1, R3.2, U5.6 (BAT)
unnamed: R5.1, U5.5 (KEY)
unnamed: L1.1, U5.7 (SW)

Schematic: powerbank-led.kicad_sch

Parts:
D13, D14, D15, D16: LED; LED_0603_1608Metric; JLC C2290
R9, R11, R12, R13: 5k1; R_0603_1608Metric; JLC C23186

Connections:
/Powerbank LED/LED1+: D13.2 (A), R11.2; also elsewhere on the board
/Powerbank LED/LED1-: D14.2 (A), D16.2 (A), R9.2, R12.2; also elsewhere on the board
/Powerbank LED/LED3+: D15.2 (A), R13.2; also elsewhere on the board
unnamed: D13.1 (K), R9.1
unnamed: D14.1 (K), R11.1
unnamed: D15.1 (K), R12.1
unnamed: D16.1 (K), R13.1

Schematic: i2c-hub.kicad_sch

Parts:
C37: 100n; C_0603_1608Metric; JLC C14663
U12: TCA9546APW; TSSOP-16_4.4x5mm_P0.65mm; JLC C42420613

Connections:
/3V3: C37.1, U12.16 (VCC); also elsewhere on the board
/SCL: U12.14 (SCL); also elsewhere on the board
/SDA: U12.15 (SDA); also elsewhere on the board
/Sensors/I2C Hub/SCL2: U12.10 (SC2)
/Sensors/I2C Hub/SCL3: U12.12 (SC3)
/Sensors/I2C Hub/SDA2: U12.9 (SD2)
/Sensors/I2C Hub/SDA3: U12.11 (SD3)
/Sensors/I2C Hub/~RESET: U12.3 (~RESET); also elsewhere on the board
/Sensors/SCL0: U12.5 (SC0); also elsewhere on the board
/Sensors/SCL1: U12.7 (SC1); also elsewhere on the board
/Sensors/SDA0: U12.4 (SD0); also elsewhere on the board
/Sensors/SDA1: U12.6 (SD1); also elsewhere on the board
GND: C37.2, U12.1 (A0), U12.2 (A1), U12.8 (GND), U12.13 (A2); also elsewhere on the board

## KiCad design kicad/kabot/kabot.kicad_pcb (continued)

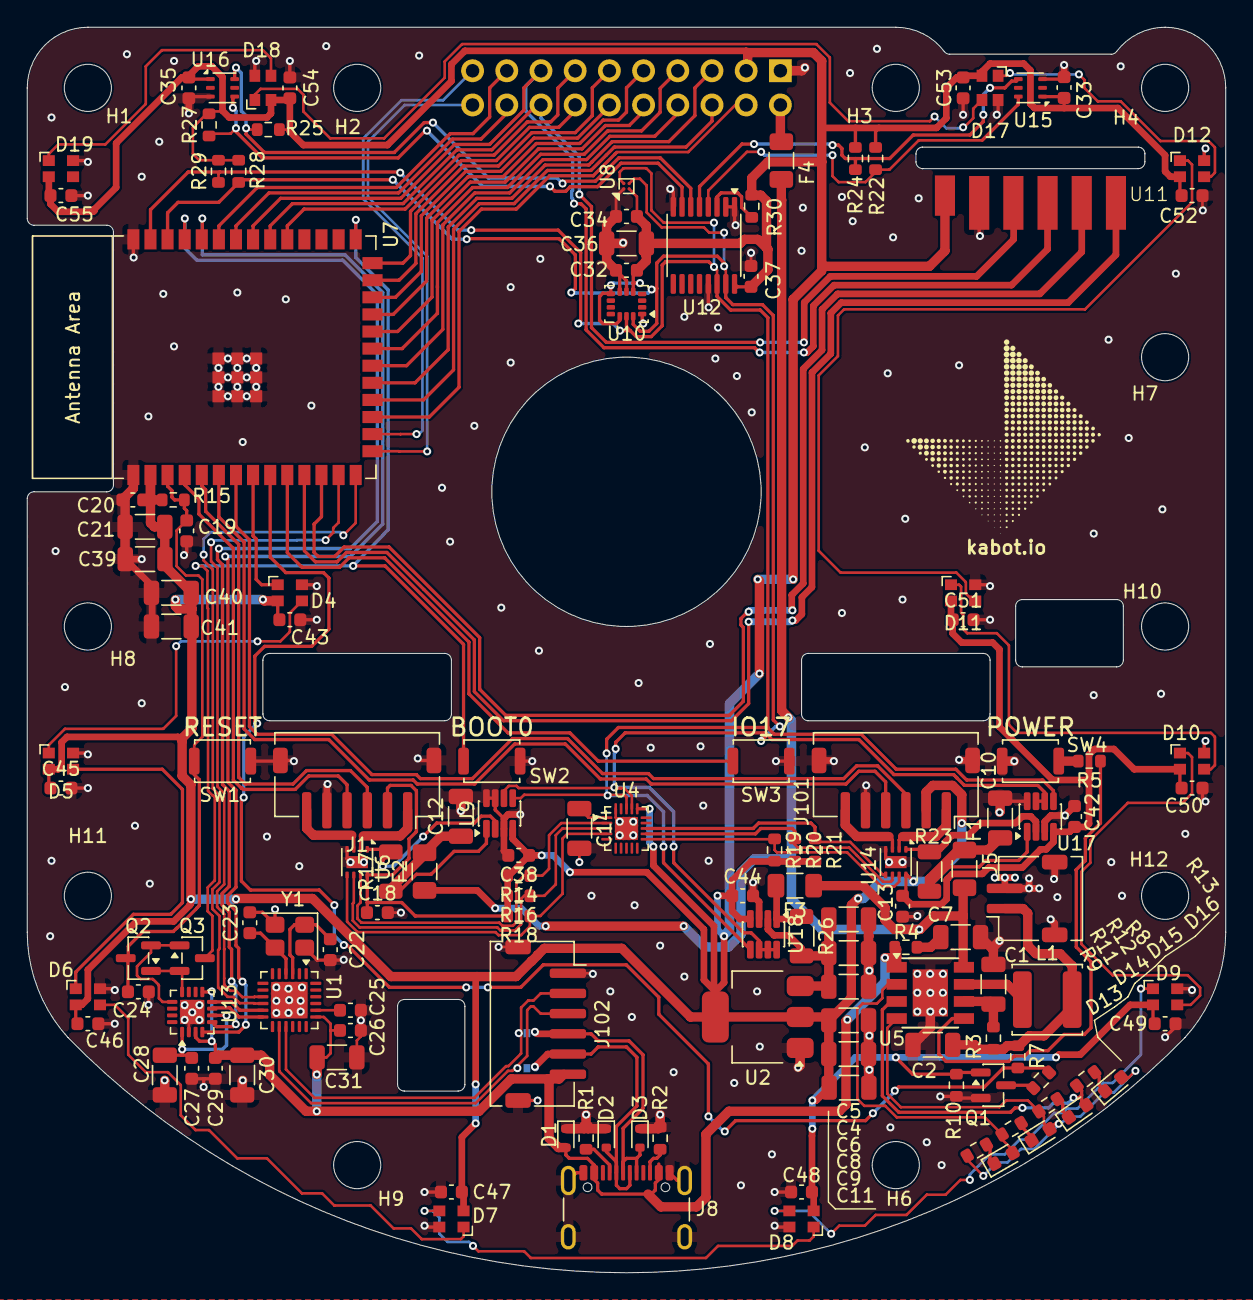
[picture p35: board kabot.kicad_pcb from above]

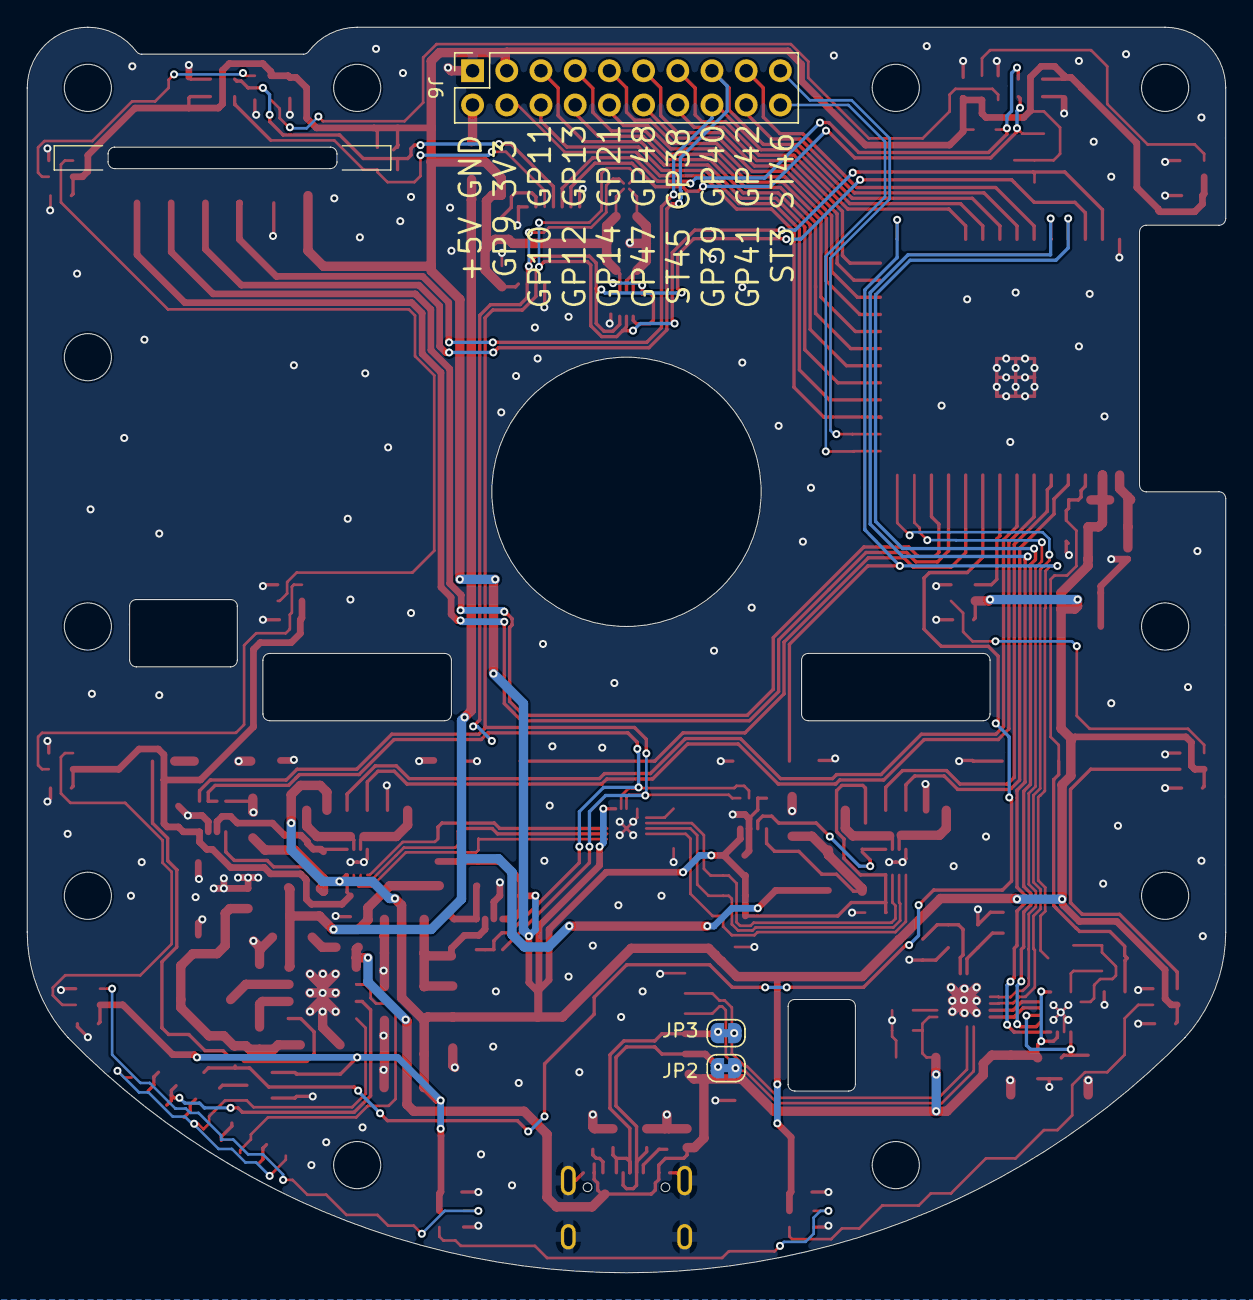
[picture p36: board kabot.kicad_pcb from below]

Board: 2 copper layers, 89.0 x 92.5 mm, 149 parts (3 on the bottom side), 100 nets.

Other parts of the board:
G1: LOGO; Logo

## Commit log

2026-07-18 feat: initial dump of KiCad project
    [Current Sensor.kicad_sch, Linear Regulator.kicad_sch, Motor Driver.json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]
2026-07-18 feat: add mechanical and production files
    [BOM-kabot.csv, Base.FCStd, Battery.FCStd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]
2026-10-09 Expand README with BOM and electronics details
    Added sections on BOM, electronics, processing, power, and sensors to README.
